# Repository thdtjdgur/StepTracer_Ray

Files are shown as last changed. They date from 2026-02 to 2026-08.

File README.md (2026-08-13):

# StepTracer_Ray

<p align="center">
  
  
  
  
</p>

StepTracer_Ray is a competition-oriented line tracer project built around repeated runs on the same track.
Instead of driving every lap with the same logic, the robot improves its strategy step by step: it first learns the course, then replays it faster, and finally applies more aggressive tuning for maximum performance.

That multi-stage race strategy is the core idea of this project.

## Hardware Image

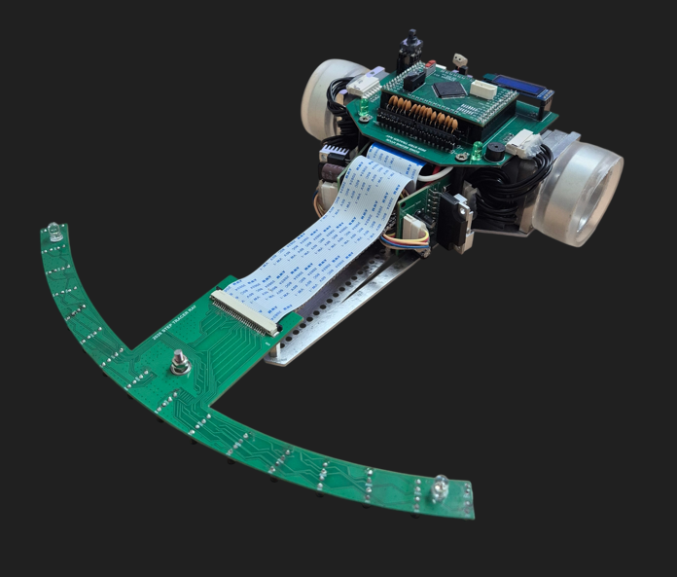
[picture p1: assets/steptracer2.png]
StepTracer hardware


## Demo Video

- 3rd race video: [`assets/videos/third-race.mp4`](assets/videos/third-race.mp4)

## PCB Files

- `HardWare/2025_PCB/`: archived PCB project files from the previous board set
- `HardWare/2026_PCB/`: updated PCB project files for `main_board.eprj`, `sensor_board.eprj`, and `motor_driver.eprj`

## Overview

The project is organized around three race stages:

- **1st race**: search and map generation
- **2nd race**: map-based fast replay
- **3rd race**: advanced tuning with trajectory shift and gain scheduling

The recorded race data is stored in `search_info[]`, which is then reused by the later runs.

## Race Strategy

### 1st Race - Search Run

The first race is the learning phase.

During this run, the robot follows the line while detecting turn marks, measuring distances between sections, and recording track information. The collected data is stored in `search_info[]` and later written to ROM so the next race can reuse the course map.

In short, the goal of the first race is reliable completion and track memorization.

### 2nd Race - Fast Run

The second race is the replay phase based on the recorded map.

After loading the saved track data, the robot classifies each section as straight, 45-degree turn, 90-degree turn, 180-degree turn, 270-degree turn, or large turn. Based on that information, it calculates acceleration, deceleration distance, entry speed, exit speed, and maximum speed for each segment.

Because the course is already known, the robot can drive more aggressively on straights and prepare for corners earlier than in the first race.

### 3rd Race - Extreme Run

The third race is the fully optimized performance phase.

This stage keeps the map-based replay logic from the second race, but adds more advanced tuning such as:

- target position shift before and after corners
- corner-group speed optimization
- adaptive `Kp` control
- more detailed acceleration planning

Instead of always following the line with the same center position, the robot intentionally shifts its trajectory depending on corner shape and surrounding track pattern. This allows faster and smoother cornering.

Related demo:

- 3rd race run video: [`assets/videos/third-race.mp4`](assets/videos/third-race.mp4)

## Core Modules

- `main.c`  
  System initialization and startup flow.

- `sensor.c`  
  Sensor sampling, normalization, line position calculation, cross detection, turn mark detection, and start/end detection.

- `Motor.c`  
  Motion control, distance accumulation, acceleration/deceleration logic, and third-race control behavior.

- `search.c`  
  First-race mapping logic.

- `fastrun.c`  
  Second-race speed planning and replay logic.

- `extremerun.c`  
  Third-race advanced tuning logic.

- `Rom.c`  
  Save/load logic for calibration data and recorded race data.

- `menu.c`  
  Menu interface for selecting race modes and tuning values.

## Technical Highlights

- 16-sensor line detection system
- weighted position calculation for smooth steering
- track memorization through first-run mapping
- turn classification based on recorded segment distance
- per-section velocity and deceleration planning
- third-run lateral shift and gain scheduling
- interrupt-driven sensor and motor control loop

## Position Low-Pass Filter

The STM32 control loop samples the line position every `200 us` (`5 kHz`). A first-order low-pass filter is used to reduce abrupt position changes and high-frequency sensor noise before the filtered position is used by the steering controller.

The continuous-time filter is

```text
         wc
H(s) = -------,    wc = 2*pi*Fc
       s + wc
```

Applying the Tustin transform

```text
    2   1 - z^-1
s = - * --------
    T   1 + z^-1
```

produces the discrete coefficients

```text
Kb = wc*T / (2 + wc*T)
Ka = (wc*T - 2) / (2 + wc*T)
```

and the difference equation

```text
y[n] = Kb * (x[n] + x[n-1]) - Ka * y[n-1]
```

which maps directly to C:

```c
filtered_position = Kb * (current_position + previous_position)
                    - Ka * previous_filtered_position;
```

With the current default `Fc = 80 Hz` and `T = 0.0002 s`, the coefficients are `Kb = 0.04786` and `Ka = -0.90428`. For a position step from `0` to `5000`, the filtered output starts approximately as `239 -> 695 -> 1107`, instead of jumping directly to `5000`.

The filtered position is used for the proportional term, while its sample-to-sample difference is used for the derivative term:

```text
P = Kp * y[n]
D = Kd * (y[n] - y[n-1])
```

The cutoff frequency `Fc` is adjustable from the OLED menu. Lower values provide stronger smoothing but slower response; higher values follow the line position faster but pass more sensor noise.

## Detailed Code Analysis

- Third-race deep dive: [`docs/extremerun-analysis.md`](docs/extremerun-analysis.md)
- Focus areas: `SofteWare/Initial_3rd_Code/main/extremerun.c` and `SofteWare/Initial_3rd_Code/main/Motor.c`

## Project Idea

This is not just a basic line follower. It is a staged racing system that combines sensing, memory, motion planning, and control tuning to improve lap performance across multiple runs.

The overall idea can be summarized as:

1. learn the course,
2. replay the course faster,
3. optimize the trajectory and control for the best run.

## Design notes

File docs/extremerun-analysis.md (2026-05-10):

# Extreme Run Code Analysis

This document explains how the third-race logic works in `SofteWare/Initial_3rd_Code/main/extremerun.c` and how that logic is executed at runtime by `SofteWare/Initial_3rd_Code/main/Motor.c`.

The third race is not just a faster second race. It adds a second layer of optimization on top of the saved map:

- straight-section acceleration is recomputed,
- corner groups get additional velocity shaping,
- lateral target shift is assigned per turn type,
- the shift is applied gradually before and after each segment midpoint,
- `Kp` is scheduled by track pattern instead of staying constant.

## Where the third race starts

The third race still enters through `fast_race()` in `SofteWare/Initial_3rd_Code/main/fastrun.c`.
When `third_val == 1`, the code runs the following pipeline before the robot starts moving:

1. `all_reset()`
2. `x_acc_func()`
3. `turn_maxvel_func()`
4. `x_maxvel_func()`
5. `chop_sdist_targetshift_func()`
6. `kp_division_func()`

After that, `StartCpuTimer2()` enables `CONTROL_ISR()`, which is the runtime loop that actually applies the third-race shift and gain scheduling.

## Key third-race fields in `search_info[]`

The third-race planner writes its results into each `race_info` entry:

- `iq10targetshift`: final lateral shift magnitude for that segment
- `iq10chop_targetshift`: one chopped piece of the target shift
- `iq10chop_shift_before`: shift increment used before the midpoint / before entering the next posture
- `iq10chop_shift_after`: shift increment used after the midpoint / while recovering or connecting to the next posture
- `iq15chop_sdist`: distance threshold that decides when the shift update begins inside the segment
- `DownFlag_U16`: whether the current pattern should drive `Kp` downward
- `Kp_UpDown_IQ17`: minimum scheduled `Kp` for the current pattern

These are later consumed by `CONTROL_ISR()` in `Motor.c`.

## Important default constants

These values are initialized mainly in `SofteWare/Initial_3rd_Code/main/search.c` and `SofteWare/Initial_3rd_Code/main/main.c`:

- `std_dist = 824`
- `iq15_chop_dist_amount = _IQ15(1000)`
- `iq10target_shift_large = _IQ10(1500)`
- `iq10target_shift_270 = _IQ10(2500)`
- `iq10target_shift_180 = _IQ10(2600)`
- `iq10target_shift_90 = _IQ10(6500)`
- `iq10target_shift_45 = _IQ10(5000)`
- `iq10target_shift_straight = _IQ10(2000)`
- `Curvature_difference = 0` by default

In practice, 90-degree turns receive the largest target shift, while large turns and straight recovery use smaller values.

## 1. `chop_sdist_targetshift_func()`

This pass assigns the shift plan for every segment.

### 1-1. What this code means

```c
_iq10 iq10_chop_shift_amount = _IQ10(1000);

pinfo->iq15chop_sdist = _IQ15div((pinfo->int32dist << 15) >> 1, iq15_chop_dist_amount);
if(((pinfo->int32dist + Curvature_difference) >> 1) < std_dist)
    iq10_chop_shift_amount = _IQ10div(
        iq10_chop_shift_amount,
        _IQ10div(std_dist << 10, (((pinfo->int32dist + Curvature_difference) << 10) >> 1))
    );
```

This block is the core of the chopped-shift planner.

- `iq10_chop_shift_amount` starts at `_IQ10(1000)`.
  - Conceptually, this is the divisor that determines how finely the target shift is sliced.
  - A larger divisor means smaller shift increments.
  - A smaller divisor means larger shift increments.

- `pinfo->iq15chop_sdist` is the distance threshold that decides when the shift update begins.
  - With the default `iq15_chop_dist_amount = _IQ15(1000)`, this becomes roughly **half of the segment distance** in IQ15 units.
  - So the third-race controller starts applying the chopped shift after about half of the segment has been traveled.

- The `if` condition checks whether **half of the adjusted segment distance** is shorter than `std_dist`.
  - Because `>>` has lower precedence than `+`, this expression is effectively:
    - `((int32dist + Curvature_difference) >> 1) < std_dist`
  - If the segment is short, the code reduces `iq10_chop_shift_amount`.

- Why reduce it?
  - Later, the code calculates `targetshift / iq10_chop_shift_amount`.
  - If the divisor becomes smaller, each chopped shift step becomes larger.
  - That means short segments apply the same lateral movement more aggressively, because there is less distance available to complete the shift.

So this block is a distance-adaptive smoothing rule:

- long segment -> smaller step per update
- short segment -> bigger step per update

### 1-2. Straight / end segment behavior

When the current segment is straight or end-turn:

- it recursively looks ahead to the next segment,
- inherits the next segment's `iq10targetshift`,
- calculates `iq10chop_shift_before` from the previous segment,
- calculates `iq10chop_shift_after` from the next segment.

This means the straight segment acts as the transition area between corners.

Instead of assigning a unique corner shift to the straight itself, the code uses the straight to:

- prepare for the previous corner's exit,
- prepare for the next corner's entry.

### 1-3. Same-direction consecutive turns

This block handles cases like right-straight-right or left-straight-left:

```c
if((((((pinfo-1)->int32turn_dir) & RIGHT_TURN) && (((pinfo+1)->int32turn_dir) & RIGHT_TURN)) ||
    ((((pinfo-1)->int32turn_dir) & LEFT_TURN) && (((pinfo+1)->int32turn_dir) & LEFT_TURN))) && (mark != 0))
```

The idea is simple:

- if two consecutive corners bend in the same direction,
- the robot should not fully return to the center and then shift again,
- it should connect those shifts more smoothly.

That is why the code sometimes uses the **difference** between neighboring `targetshift` values instead of the full previous value.

### 1-4. Opposite-direction transition case

There is also a special case for patterns that effectively behave like an S-curve:

```c
if((pinfo-1)->int32turn_way != (pinfo+1)->int32turn_way)
```

In this case the code avoids carrying too much previous-direction shift into the next opposite-direction turn.
It forces a more direct transition, often pulling the before-shift back toward zero.

### 1-5. Turn-type target shift assignment

For non-straight segments, the target shift is selected by turn class:

- `< TURN_90` -> use `iq10target_shift_45`
- `< TURN_180` -> use `iq10target_shift_90`
- `< TURN_270` -> use `iq10target_shift_180`
- `< LARGE_TURN` -> use `iq10target_shift_270`
- `END_TURN` -> use `iq10target_shift_straight`
- otherwise -> use `iq10target_shift_large`

This means the target shift is not derived from a continuous curvature estimate. It is chosen from a hand-tuned lookup by corner class.

### 1-6. `before` and `after` shift on actual turn segments

For a real turn segment:

- `iq10chop_shift_before` pushes the robot into the target posture before the turn fully develops,
- `iq10chop_shift_after` either:
  - continues the same-direction offset if another turn follows, or
  - starts recovering back toward center if the next segment is straight/end.

There is also a special half-shift rule for certain S-like combinations, which reduces the recovery amplitude to avoid overshoot.

## 2. `all_reset()`

This function resets every segment to a neutral third-race baseline.

For each `search_info[i]`, it:

- sets `int32accel = 3000`,
- sets `iq7in_vel`, `iq7vel`, and `iq7out_vel` to the base target velocity,
- clears `DownFlag_U16`,
- resets `Kp_UpDown_IQ17` to `PID_Kp_IQ17`,
- clears the chopped shift fields.

So `all_reset()` is not the final plan. It is the clean starting point before each specialized planner rewrites selected fields.

## 3. `turn_maxvel_func()` and `turn_maxvel_compute()`

This pass handles grouped-corner velocity shaping.

The main idea is:

- if several short connected turns appear close together,
- treat them as one corner group,
- compute a shared acceleration level and a shared bridge velocity.

The function uses `x_count` and `int32x_dist` to accumulate consecutive related segments.

### What it is trying to do

- skip segments that are too sharp or not useful for grouping,
- collect consecutive corner-group distance into `int32x_dist`,
- choose `int32accel` from `X_SHORT_DIST`, `X_MID_DIST`, `X_LONG_DIST`,
- compute `iq7x_vel` with `X_vel_compute()`,
- propagate that velocity as:
  - current segment `out_vel`,
  - next segment `in_vel`.

This creates smoother corner-to-corner connection speed than the plain second-race planner.

## 4. `X_vel_compute()`

This function is a third-race-specific maximum-velocity helper.

It uses the same kinematic idea as the normal fast-run planner:

- `v_next = sqrt(v_current^2 + 2 a s)`

Then it clamps the result:

- upper bound: `_IQ7(2500.0)`
- lower bound: base target velocity

So this function computes a bounded bridge velocity for grouped-corner logic.

## 5. `x_acc_func()` and `x_straight_compute()`

This pass recomputes acceleration for straight and end-turn sections only.

The logic is still distance-bucket based:

- `LONG_DIST` -> use `g_int32long_ACC + long_accel`
- `MID_DIST` -> use `g_int32mid_ACC + mid_accel`
- otherwise -> use `g_int32short_ACC + short_accel`

Special handling:

- the very first segment gets `3500 + start_accel`,
- the end segment is forced down to `2800`.

This pass is important because the third-race planner later recomputes max velocity on top of these new acceleration values.

## 6. `x_maxvel_func()` and `x_maxvel_compute()`

This pass recalculates straight-section velocity and deceleration distance after the third-race acceleration adjustments.

The flow is:

1. compare `iq7in_vel` and `iq7out_vel`
2. compute the minimum distance required to connect them via `decel_dist_compute()`
3. if the segment is too short, solve directly for reachable max velocity
4. otherwise, compute a higher `iq7vel` and then compute `iq7dec_dist`

This is the third-race version of straight-section speed planning, applied after grouped-corner tuning has already modified some boundary velocities.

## 7. `kp_division_func()` and `kp_division_compute()`

This pass schedules `Kp` according to corner pattern.

### Big picture

The intent is:

- simple or isolated sections keep the default `PID_Kp_IQ17`,
- dense corner patterns lower `Kp` in a controlled way,
- sharp transitions receive a more aggressive minimum `Kp` profile.

### Pattern examples

The code explicitly handles pattern families such as:

- straight-short-45
- 45-45
- 45-45-45-45
- 45-90 combinations
- 90-45 combinations
- 90-90 combinations

And it assigns tuned constants such as:

- `Kp_S4_IQ17`
- `Kp_SHORT_S44S_IQ17`
- `Kp_long_S44S_IQ17`
- `Kp_S4444S_IQ17`
- `Kp_SHARP_TURN_IQ17`
- `Kp_S9999S_IQ17`

`DownFlag_U16` marks whether the runtime controller should move `HanPID.Kp_val_IQ17` downward toward the chosen minimum.

### Important note

This line is logically wrong:

```c
if(search_info[i].int32turn_dir != STRAIGHT || search_info[i].int32turn_dir != END_TURN)
```

It is always true, because one value cannot be both `STRAIGHT` and `END_TURN` at the same time.
The condition almost certainly should have been `&&` instead of `||`.

So `kp_division_compute()` currently runs for every segment, even when the author probably intended to filter out straight/end segments.

## 8. `xCONTROL()`

This function is the runtime `Kp` ramp controller.

Inputs:

- `mode`
- `ratio`
- `kp_min`

Behavior:

- `mode == OFF`
  - increase `Kp_val_IQ17` toward `PID_Kp_IQ17`
- `mode == ON`
  - decrease `Kp_val_IQ17` toward `kp_min`

The per-update step size is:

```c
_IQ17mpy(ratio, _IQ17(0.823882502))
```

The `0.823882502` constant matches the per-step travel distance used elsewhere in the code. So the ramp is effectively distance-based, even though it is applied inside an interrupt loop.

This is a key design choice: the code tries to make `Kp` transition with travel progress, not as a one-shot jump.

## 9. `underdist()`

This helper precomputes error thresholds used during replay:

- `under_dist = 70% of expected segment distance`
- `err_dist = expected segment distance + 150 mm`

So the third-race error logic has both:

- an early-arrival threshold,
- an overrun threshold.

## 10. Runtime behavior in `Motor.c::CONTROL_ISR()`

This is where the third-race plan becomes actual control output.

## 10-1. `Kp` ramp application

At the top of the ISR:

```c
if(search_info[U16_3rd_turnmark_cnt].DownFlag_U16)
    xCONTROL(ON, &HanPID, KP_D_RATIO_IQ17, search_info[U16_3rd_turnmark_cnt].Kp_UpDown_IQ17);
else
    xCONTROL(OFF, &HanPID, KP_U_RATIO_IQ17, search_info[U16_3rd_turnmark_cnt].Kp_UpDown_IQ17);
```

Meaning:

- if the current pattern requires `Kp` reduction, move toward the segment-specific minimum,
- otherwise recover back toward the normal base `Kp`.

So `kp_division_compute()` is the planner, and `xCONTROL()` inside `CONTROL_ISR()` is the actuator.

## 10-2. Per-segment distance reset

When `third_turnmark_flag` is `OFF`, the ISR resets:

- `LMotor.iq15third_gone_dist`
- `RMotor.iq15third_gone_dist`

Then it sets `third_turnmark_flag = ON`.

This creates a fresh local distance counter for the current third-race segment.

## 10-3. Before / after split

The ISR calculates:

- `iq15third_dist_sum`: local distance used against `iq15chop_sdist`
- `iq15third_dist_sum_dupli`: average real distance used for before/after classification

Then it decides:

- `before = ON`, `after = OFF` if current progress is still in the first half of the segment
- otherwise `before = OFF`, `after = ON`

So the segment is split into two logical zones around its midpoint.

## 10-4. When the shift actually starts

The ISR does **not** update `iq10position_shift` immediately.
It first waits until:

```c
iq15third_dist_sum > search_info[U16_3rd_turnmark_cnt].iq15chop_sdist
```

Since `iq15chop_sdist` is roughly half the segment distance, this means the actual shift update starts around the second half of the local segment progress.

That prevents abrupt lateral movement immediately after a mark transition.

## 10-5. Straight / end segment shift update

If the current segment is straight or end-turn:

- `before` applies `iq10chop_shift_before`
- `after` applies `iq10chop_shift_after`

Then the code clamps `iq10position_shift` so it does not overshoot the allowed target derived from neighboring corners.

This is why the straight segment behaves like a transition buffer between turns.

## 10-6. Actual turn segment shift update

If the current segment is a turn:

- `before` moves the shift toward the current turn's target posture,
- `after` either recovers toward straight or connects to the next turn posture,
- additional clamps limit overshoot for same-direction chains and opposite-direction patterns.

So the runtime shift is not a single setpoint jump. It is a staged position migration with context-aware saturation.

## 10-7. Why `g_Flag.third_turnmark_flag` is cleared at the end

At the end of the update block:

```c
g_Flag.third_turnmark_flag = OFF;
```

This forces the next cycle after a segment transition to reset the local third-race distance counters again.
That is how each segment gets its own local shift timing window.

## Putting it all together

The full third-race behavior is:

1. reuse the first-race map and second-race turn classification
2. re-plan straight acceleration and grouped-corner speed
3. assign a lateral target shift by turn class
4. break that shift into before/after chopped increments
5. schedule `Kp` by corner pattern
6. inside `CONTROL_ISR()`, ramp `Kp` and apply lateral shift gradually based on segment progress

In other words, the third race does not simply "go faster." It changes how the robot places itself on the line and how stiffly it responds while entering, connecting, and leaving corner patterns.

## Important quirks and possible issues

- `kp_division_func()` uses an always-true `||` condition and likely needs `&&`.
- Several expressions in `turn_maxvel_compute()` rely on mixed `&&` and `||` without extra parentheses, so the actual grouping may not exactly match the author's comments.
- The planner is heavily pattern-based and hand-tuned, so behavior depends strongly on the exact turn classification from the second-race map.
- The straight recursion in `chop_sdist_targetshift_compute()` assumes a valid next entry exists; this works only if the race table has been built consistently.

## Bottom line

`extremerun.c` is a post-planner for the third race.
It does three main things:

- rebuilds speed decisions for difficult corner groups,
- precomputes how much lateral shift each segment should create,
- precomputes how `Kp` should be lowered and restored.

`Motor.c::CONTROL_ISR()` is the executor.
It applies those plans gradually while the robot is physically moving through each segment.

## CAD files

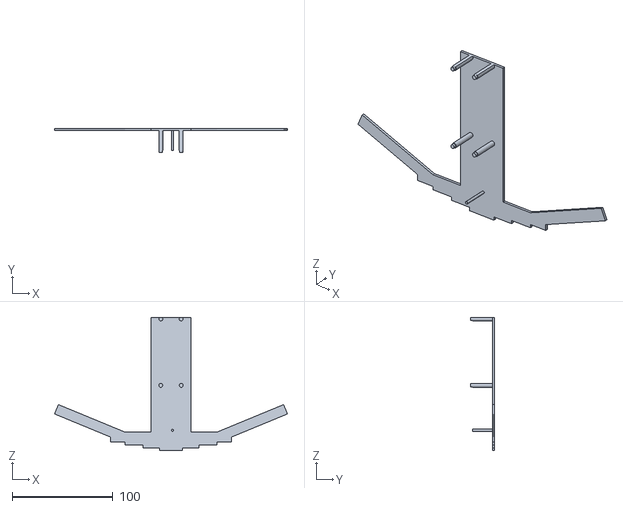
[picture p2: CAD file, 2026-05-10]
Mechanics/STL/송성혁_센서보드.STL
231.6 x 24.0 x 132.6

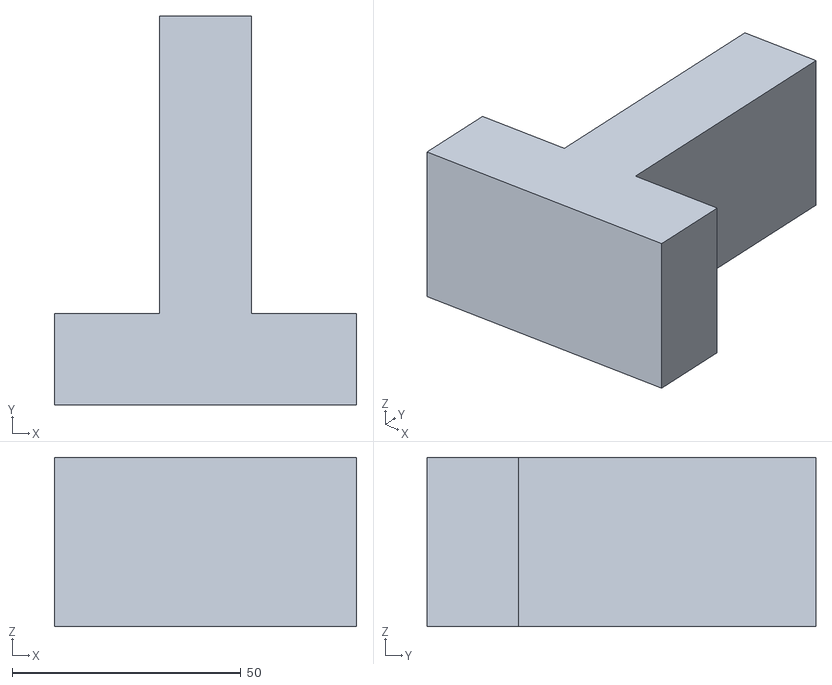
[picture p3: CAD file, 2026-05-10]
Mechanics/STL/송성혁_배터리.STL
66.0 x 85.0 x 37.0

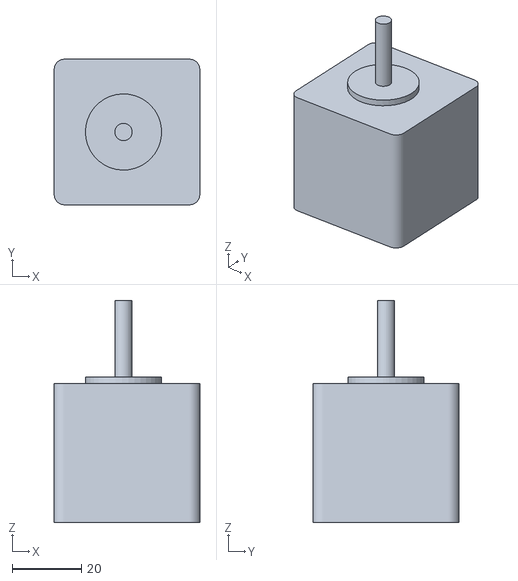
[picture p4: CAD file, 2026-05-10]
Mechanics/STL/송성혁_모터.STL
42.0 x 42.0 x 64.0

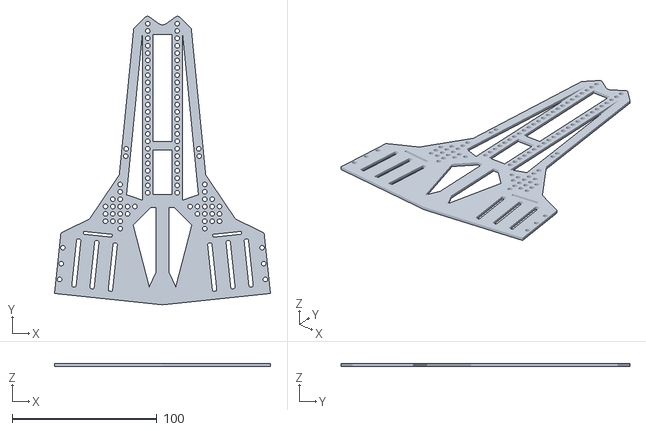
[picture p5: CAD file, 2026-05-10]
Mechanics/STL/26년 스텝밑판.STL
149.2 x 199.3 x 2.00

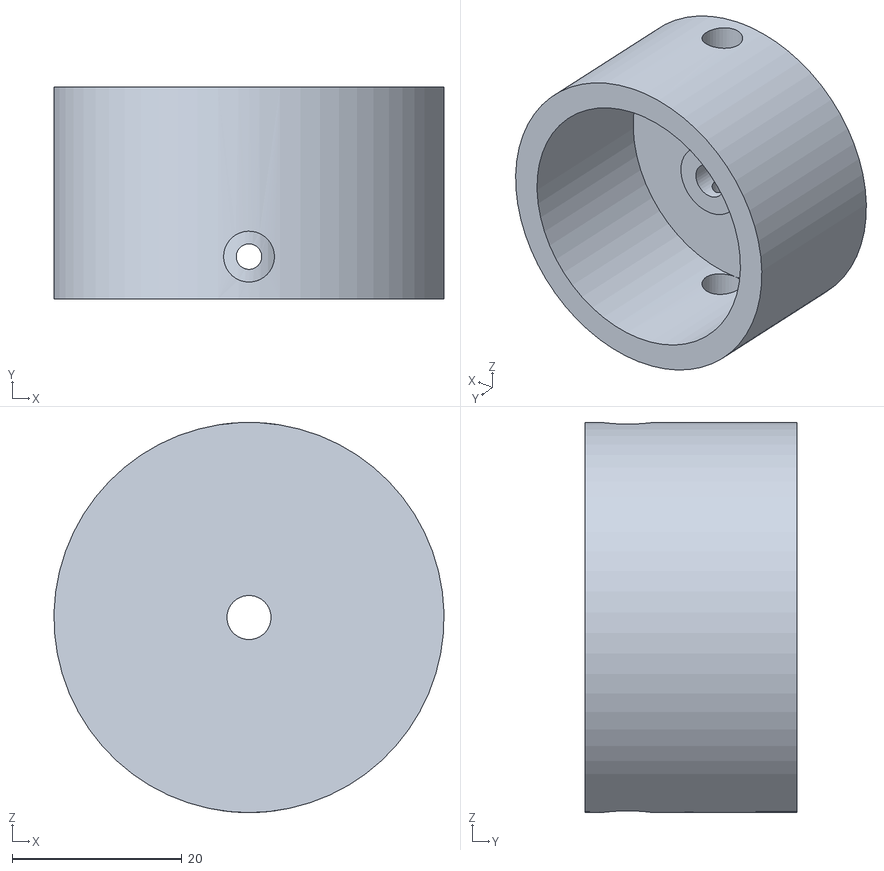
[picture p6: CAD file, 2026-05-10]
Mechanics/STL/송성혁_바퀴.STL
46.0 x 25.0 x 46.0

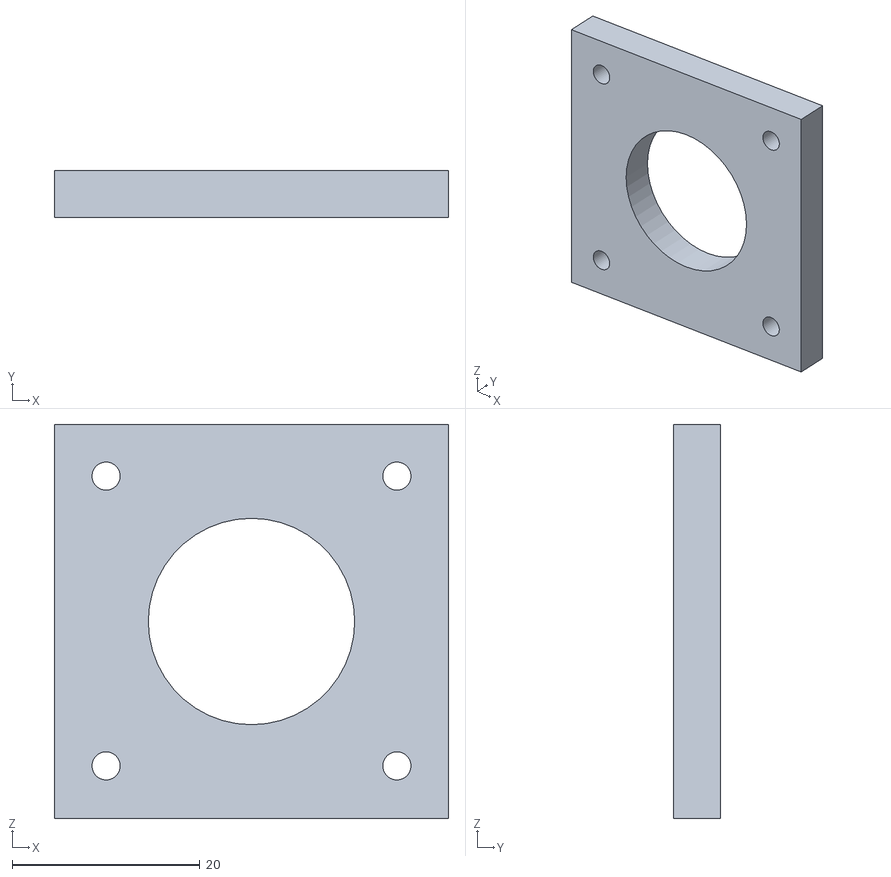
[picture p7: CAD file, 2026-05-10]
Mechanics/STL/송성혁_가드.STL
42.0 x 5.00 x 42.0

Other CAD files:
SofteWare/Tms_Initial_3rd_Code/main/main.obj
SofteWare/2025_dankook_code/main/main.obj
SofteWare/Tms_Initial_3rd_Code/main/DSP280x_CpuTimers.obj
SofteWare/Tms_Initial_3rd_Code/main/DSP280x_Sci.obj
SofteWare/Tms_Initial_3rd_Code/main/extremerun.obj
SofteWare/Tms_Initial_3rd_Code/main/DSP280x_usDelay.obj
SofteWare/Tms_Initial_3rd_Code/main/VFD.obj
SofteWare/Tms_Initial_3rd_Code/main/DSP280x_PieCtrl.obj
SofteWare/Tms_Initial_3rd_Code/main/search.obj
SofteWare/Tms_Initial_3rd_Code/main/DSP280x_Adc.obj
SofteWare/Tms_Initial_3rd_Code/main/Motor.obj
SofteWare/Tms_Initial_3rd_Code/main/DSP280x_MemCopy.obj
SofteWare/2025_dankook_code/main/DSP280x_Adc.obj
SofteWare/2025_dankook_code/main/DSP280x_CodeStartBranch.obj
SofteWare/2025_dankook_code/main/DSP280x_CpuTimers.obj
SofteWare/2025_dankook_code/main/DSP280x_DefaultIsr.obj
SofteWare/2025_dankook_code/main/DSP280x_EPwm.obj
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

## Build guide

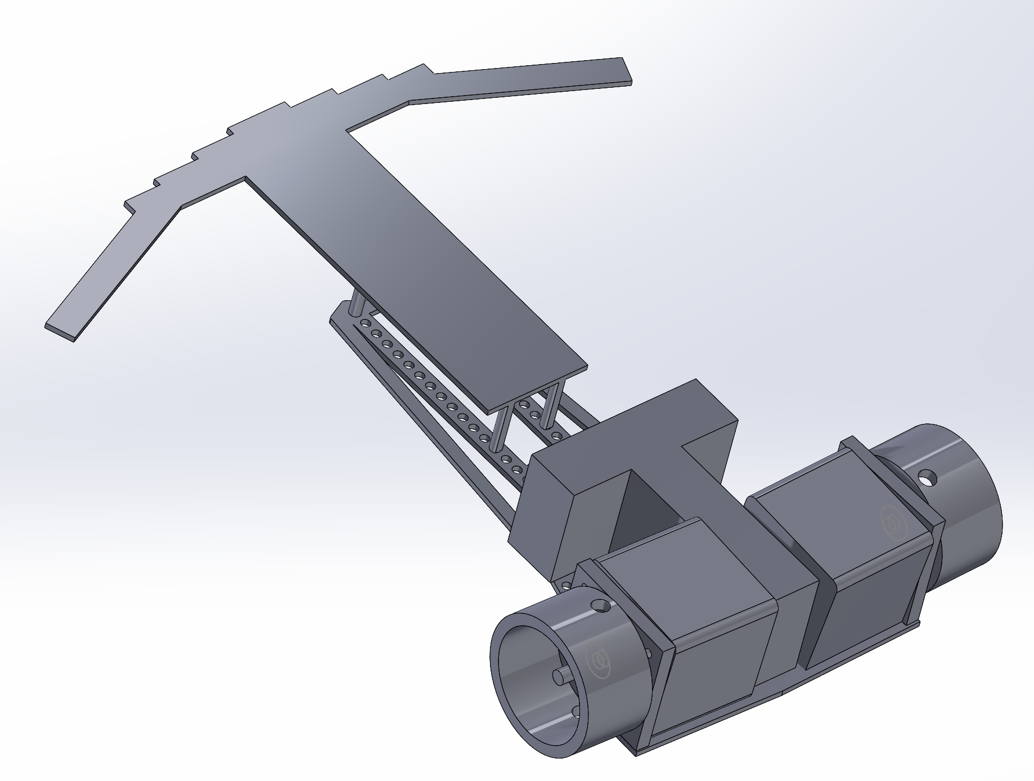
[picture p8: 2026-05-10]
Mechanics/Assembly.png

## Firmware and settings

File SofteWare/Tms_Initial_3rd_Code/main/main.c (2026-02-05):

#define _MAIN_
#define __STRUCT__


#include "DSP280x_Device.h"     // DSP281x Headerfile Include File
#include "DSP280x_Examples.h"  // DSP281x Examples Include File

void System_Init(void)
{
	DINT;				// 전체 인터럽트 금지
	InitSysCtrl();		// 워치록 금지, PLL 초기화, 주변 장치 클럭설정
	InitGpio();			// 입출력 포트 초기화	
	InitCpuTimers();
	
	MemCopy(&RamfuncsLoadStart, 	&RamfuncsLoadEnd, 		&RamfuncsRunStart); 
	MemCopy(&RamfuncsLoadStart1, 	&RamfuncsLoadEnd1, 	&RamfuncsRunStart1);
	
	InitSci();			
	InitSpi();
	InitPieCtrl();		// PIE 제어 레지스터 초기화 동작
	IER = 0x0000;		// 인터럽트 인에이블 레지스터 클리어
	IFR = 0x0000;		// 인터럽트 플래그 레지스터 클리어
	InitPieVectTable();
	InitAdc();

	Init_ISR();

	InitEPWM( &LeftPwmRegs );
	InitEPWM( &RightPwmRegs );
	
	InitEQep( &LeftQepRegs );
	InitEQep( &RightQepRegs );
	
}

void Variable_Init( void )
{
    memset( ( void * )search_info, 0x00, sizeof( race_info ) * 256 );//초기화 함수
	g_int32_sen_cnt = 0;
	g_int32_copmare_cnt = 0;
	g_u16pos_cnt=6;
	
	g_pos.iq10temp_position= _IQ10(0.0);
	g_pos.iq7temp_pos = _IQ7(0.0);
	g_u16pos_cnt=6;
	g_int32_turnmark_cnt = 0;
	g_int32_lineout_cnt = 0;
	g_int32_start_end_cnt = 0;
	g_u32_ACC_targetval=3700;//트레이서 가속도 
	g_u32_VEL_targetval=2000;//트레이서 속도//2200
	g_u32_END_ACC_targetval = 9000;//(g_u32_VEL_targetval * g_u32_VEL_targetval / 435);//2as==v^2-v0^2 에서 가속도를 구하는 공식 

	g_q17_handle_acc = _IQ17(0.00002960);
	g_q17_handle_dec = _IQ17(0.0002560);//올려보자	
	g_Flag.motor = OFF;
	interrupt_flag = ON;
	
	g_u16turn_dist = T___dist = 67;//65:txprint잛은거임//txprint긴거 할대는 60가지 줄이기
	third_dist_err = 100;//조금더 시프팅을 일직하고싶다면 늘리기. 가상의 턴마크를 옮기는 역할
	Curvature_difference = 0;//50//실제곡률과 3차주행의 곡률차. 너무 발리 after에서 중앙으로 복귀하면 늘리기
	//serial plot의 shfit의 윗부분이 사다리골 모양이면 사다리골 윗부분을 곡짓점으로 만들기 위해 늘려야함(시프트변화속도를 늦춘다)
	//근데 곡짓점(경사가 완만 )이 되면 곡선의 완전 처음부분에서 곡선을 다라가는 경향이 생겨서 어느정도 사다리골이 되어야함 
	//즉 곡선을 다라간다싶으면 안다라가게 하기위해 줄이기 
    
    Turn_Cnt = 147;//147
	g_u32_second_END_ACC_targetval = 11500;
	end_cnt = 0;

	error = 0;
	end_accel = start_accel = long_accel = mid_accel = short_accel = 0;

    g_err.int32err_cnt = 0;
        
	acc = 0;
	dec = 0;

	second_val = 0;
	third_val = 0;
}

void main(void)
{	
	int i;

	System_Init();
	Variable_Init();
	StartCpuTimer0();
	Race_Init();
	sen_vari_init();	
	maxmin_read_rom();
	read_mark_cnt_rom();
	//StartCpuTimer2();
	//LED_ALL_OFF33;

	VFD_SENSOR();

}


void Delay(Uint32 Cnt)
{
	while(Cnt--)
	{
		asm("		nop");
		
		asm("	nop");	
	}
}

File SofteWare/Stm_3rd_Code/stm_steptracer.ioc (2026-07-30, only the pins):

Mcu.UserName=STM32G474VETx
PA0.Signal=ADC1_IN1
PA1.Signal=ADC1_IN2
PA10.Signal=USART1_RX
PA11.Signal=GPIO_Output
PA12.Signal=GPIO_Output
PA13.Signal=SYS_JTMS-SWDIO
PA14.Signal=SYS_JTCK-SWCLK
PA2.Signal=ADC1_IN3
PA3.Signal=ADC1_IN4
PA4.Signal=ADC2_IN17
PA5.Signal=ADC2_IN13
PA6.Signal=ADC2_IN3
PA7.Signal=ADC2_IN4
PA8.Signal=GPIO_Output
PA9.Signal=USART1_TX
PB0.Signal=ADC1_IN15
PB1.Signal=ADC1_IN12
PB2.Signal=S_TIM20_CH1
PB3.Signal=SPI1_SCK
PB4.Signal=SPI1_MISO
PB5.Signal=SPI1_MOSI
PC0.Signal=ADC1_IN6
PC1.Signal=ADC1_IN7
PC11.Signal=GPIO_Output
PC14-OSC32_IN.Signal=GPIO_Input
PC15-OSC32_OUT.Signal=GPIO_Input
PC2.Signal=ADC1_IN8
PC3.Signal=ADC1_IN9
PC4.Signal=ADC2_IN5
PC5.Signal=ADC2_IN11
PC6.Signal=S_TIM8_CH1
PC7.Signal=GPIO_Output
PC8.Signal=I2C3_SCL
PC9.Signal=I2C3_SDA
PD10.Signal=GPIO_Output
PD11.Signal=GPIO_Output
PD12.Signal=GPIO_Output
PD13.Signal=GPIO_Output
PD14.Signal=GPIO_Output
PD15.Signal=GPIO_Output
PD7.Signal=GPIO_Output
PD8.Signal=GPIO_Output
PD9.Signal=GPIO_Output
PE8.Signal=GPIO_Output
PE9.Signal=GPIO_Output
PF0-OSC_IN.Signal=RCC_OSC_IN
PF10.Signal=GPIO_Input
PF2.Signal=GPIO_Output
PF9.Signal=GPIO_Input

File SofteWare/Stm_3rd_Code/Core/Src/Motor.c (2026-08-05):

#include "Motor.h"

#include "extremerun.h"
#include "stm32g4xx_ll_cortex.h"
#include "stm32g4xx_ll_tim.h"

#include <math.h>
#include <string.h>

extern TIM_HandleTypeDef htim7;
extern TIM_HandleTypeDef htim8;
extern TIM_HandleTypeDef htim20;

#define LEFT_MOTOR_STOP_GPIO_Port   GPIOA
#define LEFT_MOTOR_STOP_Pin         GPIO_PIN_8
#define LEFT_MOTOR_DIR_GPIO_Port    GPIOC
#define LEFT_MOTOR_DIR_Pin          GPIO_PIN_7

#define RIGHT_MOTOR_STOP_GPIO_Port  GPIOE
#define RIGHT_MOTOR_STOP_Pin        GPIO_PIN_8
#define RIGHT_MOTOR_DIR_GPIO_Port   GPIOE
#define RIGHT_MOTOR_DIR_Pin         GPIO_PIN_9

#define MOTOR_STOP_ENABLE_STATE     GPIO_PIN_RESET
#define MOTOR_STOP_DISABLE_STATE    GPIO_PIN_SET

#define LEFT_MOTOR_FORWARD_STATE    GPIO_PIN_RESET
#define RIGHT_MOTOR_FORWARD_STATE   GPIO_PIN_SET

#define MOTOR_TIMER_CLOCK_FALLBACK  170000000u
#define MOTOR_START_VELO_MM_S     100.0f
#define STM_THIRD_CONTROL_PERIOD_US 150.0f
#define TMS_THIRD_CONTROL_PERIOD_US 200.0f
#define THIRD_KP_PERIOD_SCALE \
    (STM_THIRD_CONTROL_PERIOD_US / TMS_THIRD_CONTROL_PERIOD_US)

volatile MOTORCTRL LMotor;
volatile MOTORCTRL RMotor;

volatile uint32_t JERK_U32 = 8000u;
volatile uint32_t JERK_LONG_U32 = 20000u;
volatile uint32_t JERK_MIDDLE_U32 = 25000u;
volatile uint32_t JERK_SHORT_U32 = 30000u;

volatile uint32_t MOTOR_SPEED_U32 = 2000u;
volatile uint32_t SECOND_MAX_SPEED_U32 = 4000u;
volatile uint32_t END_SPEED_U32 = 2000u;

volatile int32_t ACCEL_COEF_I32 = 296;
volatile int32_t DECEL_COEF_I32 = 256;
volatile int32_t D_RATIO_I32 = 3.5;
volatile int32_t U_RATIO_I32 = 3.5;
volatile uint32_t Down_Kp_U32 = 5u;
volatile uint32_t SHARP_KP_U32 = 40u;   //30u
volatile uint32_t S44S_KP_U32 = 72u;
volatile uint32_t S44S_short_KP_U32 = 16u;//6u
volatile uint32_t S44S_long_KP_U32 = 16u;//6u
volatile uint32_t S4444S_KP_U32 = 47u;  //37u
volatile uint32_t S4_KP_U32 = 35u;  //29u
volatile uint32_t S9999S_KP_U32 = 5u;
volatile uint32_t mid_long_straight = 47u;//37u
volatile uint32_t short_straight = 47u;//37u 
volatile uint32_t s44s_end_s = 50u;

static uint32_t motor_timer_clock_hz = MOTOR_TIMER_CLOCK_FALLBACK;

static volatile float control_last_distance;
static volatile float control_shift_distance;
static volatile float control_position_shift;
static volatile uint16_t control_segment;
static volatile uint16_t control_soft_safe_active;
static volatile uint16_t control_soft_safe_start_segment;

static uint16_t control_total_count(void)
{
    if (g_int32total_cnt < 0)
    {
        return 0u;
    }
    if (g_int32total_cnt > 253)
    {
        return 253u;
    }
    return (uint16_t)g_int32total_cnt;
}

static float motor_clamp_float(float value, float min_value, float max_value)
{
    if (value < min_value)
    {
        return min_value;
    }

    if (value > max_value)
    {
        return max_value;
    }

    return value;
}

static float motor_valid_handle(float handle)
{
    if (!isfinite(handle))
    {
        return 1.0f;
    }

    return (handle < 0.0f) ? 0.0f : handle;
}

static uint32_t motor_get_apb2_timer_clock_hz(void)
{
    uint32_t pclk = HAL_RCC_GetPCLK2Freq();
    if (pclk == 0u)
    {
        return MOTOR_TIMER_CLOCK_FALLBACK;
    }

    if ((RCC->CFGR & RCC_CFGR_PPRE2) != RCC_CFGR_PPRE2_DIV1)
    {
        pclk *= 2u;
    }

    return pclk;
}

static float motor_min_period_counts(void)
{
    return (MOTOR_STEP_DISTANCE_MM / MAX_VELO) * (float)motor_timer_clock_hz;
}

static float motor_max_period_counts(void)
{
    return (float)MOTOR_TIMER_MAX_PERIOD_TICKS *
           (float)(1u << CLK_DIVISION_CONSTANT);
}

static float motor_period_seconds_from_ctrl(volatile MOTORCTRL *pM)
{
    float raw_counts = pM->PwmTBPRDdiv10000 * 10000.0f;
    if (raw_counts <= 0.0f)
    {
        raw_counts = motor_max_period_counts();
    }

    return raw_counts / (float)motor_timer_clock_hz;
}

static float motor_raw_counts_from_velocity(float velocity_mm_s)
{
    float velocity = motor_clamp_float(velocity_mm_s, MIN_VELO, MAX_VELO);
    return (MOTOR_STEP_DISTANCE_MM / velocity) * (float)motor_timer_clock_hz;
}

static void motor_apply_period_counts(volatile MOTORCTRL *pM, TIM_HandleTypeDef *htim, float raw_counts)
{
    uint8_t clk = pM->ClkDiv;
    const float min_counts = motor_min_period_counts();
    const float max_counts = motor_max_period_counts();
    uint32_t divider;
    uint32_t old_prescaler;
    uint32_t new_prescaler;
    uint32_t period_ticks;
    uint32_t arr;

    raw_counts = motor_clamp_float(raw_counts, min_counts, max_counts);

    while ((clk > 0u) && (raw_counts < (min_counts * (float)(1u << clk))))
    {
        clk--;
    }

    while ((clk < CLK_DIVISION_CONSTANT) &&
           (raw_counts > ((float)MOTOR_TIMER_MAX_PERIOD_TICKS *
                          (float)(1u << clk))))
    {
        clk++;
    }

    divider = 1u << clk;
    period_ticks = (uint32_t)((raw_counts / (float)divider) + 0.5f);

    if (period_ticks < 1u)
    {
        period_ticks = 1u;
    }
    else if (period_ticks > MOTOR_TIMER_MAX_PERIOD_TICKS)
    {
        period_ticks = MOTOR_TIMER_MAX_PERIOD_TICKS;
    }
    arr = period_ticks - 1u;

    pM->ClkDiv = clk;
    pM->PwmTBPRDdiv10000 = raw_counts / 10000.0f;
    pM->PrdNext = period_ticks;

    old_prescaler = htim->Instance->PSC;
    new_prescaler = divider - 1u;
    htim->Instance->PSC = new_prescaler;
    htim->Instance->ARR = arr;
    htim->Instance->CCR1 = period_ticks >> 1;

    if ((htim->Instance->CR1 & TIM_CR1_CEN) == 0u)
    {
        htim->Instance->CNT = 0u;
        htim->Instance->EGR = TIM_EGR_UG;
        htim->Instance->SR &= ~TIM_SR_UIF;
    }
    else if (old_prescaler != new_prescaler)
    {
        const uint32_t original_urs = htim->Instance->CR1 & TIM_CR1_URS;

        SET_BIT(htim->Instance->CR1, TIM_CR1_URS);
        htim->Instance->EGR = TIM_EGR_UG;
        htim->Instance->SR &= ~TIM_SR_UIF;
        if (original_urs == 0u)
        {
            CLEAR_BIT(htim->Instance->CR1, TIM_CR1_URS);
        }
    }
}

static uint32_t motor_profile_lock(void)
{
    const uint32_t primask = __get_PRIMASK();

    __disable_irq();
    return primask;
}

static void motor_profile_unlock(uint32_t primask)
{
    if (primask == 0u)
    {
        __enable_irq();
    }
}

static uint8_t motor_pwm_is_running(void)
{
    return (((htim8.Instance->CR1 & TIM_CR1_CEN) != 0u) &&
            ((htim20.Instance->CR1 & TIM_CR1_CEN) != 0u) &&
            (g_Flag.motor != OFF))
               ? 1u
               : 0u;
}

static float motor_start_velocity_for_target(float target_velocity)
{
    if (target_velocity <= MIN_VELO)
    {
        return 0.0f;
    }

    return (target_velocity < MOTOR_START_VELO_MM_S)
               ? target_velocity
               : MOTOR_START_VELO_MM_S;
}
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

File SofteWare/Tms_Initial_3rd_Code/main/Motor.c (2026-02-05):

//###########################################################################
//
// FILE		: Motor.c
//
// TITLE	: Motor c file.
//
// Author	: Yuk Keun Ho
//
// Company	: Maze & Hz
//
//###########################################################################
// $Release Date: 2011.10.16 $
//###########################################################################

#define   _MOTOR_


#include "DSP280x_Device.h"
#include "DSP280x_Examples.h"   // DSP280x Examples Include File
#include "Main.h"
#include "Motor.h"

void R_VELOCITY(void)
{
	VFDPrintf("v=%lu",g_u32_VEL_targetval);

    while(1)
    	{
    	while(1)
    		{    

	            if((SW_R==0)||(SW_L==0))// right
	            {
                    if(SW_R==0)// right
	                {
	                    DELAY_US(SW_DELAY);
		                g_u32_VEL_targetval+=50;
                    }
                    else if(SW_L==0)// right
	                {
	                    DELAY_US(SW_DELAY);
		                g_u32_VEL_targetval-=50;
                    }
					
                    VFDPrintf("v=%lu",g_u32_VEL_targetval);

					if(g_u32_VEL_targetval==1600) //속도 1600
				    {
						g_q17_handle_acc = _IQ17(0.00002970);
						g_q17_handle_dec = _IQ17(0.0002550);
					}
				    else if(g_u32_VEL_targetval==1800)//속도 1800
				    {
                        g_q17_handle_acc = _IQ17(0.00003040);
	                    g_q17_handle_dec = _IQ17(0.0002500);
					}
                    else if(g_u32_VEL_targetval==1900)//속도 1900
				    {
                        g_q17_handle_acc = _IQ17(0.00003030);//3040
	                    g_q17_handle_dec = _IQ17(0.0002670);//2500
					}
					else if(g_u32_VEL_targetval==2000)
				    {
                        g_q17_handle_acc = _IQ17(0.00003025);//3025
	                    g_q17_handle_dec = _IQ17(0.0002660);//2660
					}
					else if(g_u32_VEL_targetval==2100)//속도 2100
				    {
                        g_q17_handle_acc = _IQ17(0.00003080);//3003
	                    g_q17_handle_dec = _IQ17(0.0002500);//
					}
					else if(g_u32_VEL_targetval==2200)//속도 2200
				    {
                        g_q17_handle_acc = _IQ17(0.00003003);//3003
	                    g_q17_handle_dec = _IQ17(0.0002641);//2641
	                    g_q17_handle_dec += 12;//+1
					}
					else if(g_u32_VEL_targetval==2300)//속도 2300//acc만  1내리니가 잘감
				    {
				      	g_q17_handle_acc = _IQ17(0.00002998);// 2올림 5올림 //2998//7
				      	g_q17_handle_acc -= 0;//-1
	                    g_q17_handle_dec = _IQ17(0.0002603);// 5올림 2올림 //52
	                    g_q17_handle_dec += 18;// 12,14,16   //16, 14
					}
					else if(g_u32_VEL_targetval==2350)//속도 2350
				    {
				      	g_q17_handle_acc = _IQ17(0.00002998);// 2올림 5올림 //2998
				      	g_q17_handle_acc -= 0;//-1
	                    g_q17_handle_dec = _IQ17(0.0002603);// 5올림 2올림 
	                    g_q17_handle_dec += 0;//5, 7,8, 6666, 55555555555555555, 7777777777777낫베드, 4낫베드, 2낫베드, 1낫베드,3
					}
					else if(g_u32_VEL_targetval==2400) //acc만 2내리니가 잘감//살작 불안정함 acc를 1내리고 dec를 1올려보자.
				    {
				      	g_q17_handle_acc = _IQ17(0.00002990);//0.00002990
						g_q17_handle_acc -= 3;// -3
	                    g_q17_handle_dec = _IQ17(0.0002570);
						g_q17_handle_dec += 4;// +8(올리면 올릴수록 물방울에서 더 안죽음, 근데 올리다 보면 통통튐....5,6정도가 많이 튕기진 않는데 물방울에서 위태위태함)
					}
					else
	                {
	                    VFDPrintf("v=%lu",g_u32_VEL_targetval);
	                }
	            }


	            else if(SW_D==0)
	            {
	            	DELAY_US(SW_DELAY);
	            	VFDPrintf("v=%lu",g_u32_VEL_targetval);
			    	break;
	            }

				else if(SW_U==0)
				{
					DELAY_US(SW_DELAY);
					VFD_RUN();
				}
			
	            else
	            {
	            	VFDPrintf("v=%lu",g_u32_VEL_targetval);
	            }
                
    		}
         	//write_vel_rom();
		 	break;
    	}	
	R_MOT_A();	
}



void R_MOT_A(void)// 증가 가속도 조절 함수 
{
	VFDPrintf("HanAccel");
    while(1)
    	{
    	while(1)
    		{
    		    DELAY_US(100000);
	            if(SW_R==0)//right
	            {
	            	DELAY_US(50000);
		        	g_q17_handle_acc += 1;
                	acc+=1;
                	VFDPrintf("acc_%d   ",acc);
	            }

	            else if(SW_L==0)//left
	            {
	            	DELAY_US(50000);
		        	g_q17_handle_acc -= 1;
                	acc-=1;
                	VFDPrintf("acc_%d   ",acc);
		        }

	            else if(SW_D==0)//down
	            {
	            	DELAY_US(SW_DELAY);
	            	VFDPrintf("acc_%d   ",acc);
			    	break;
	            }

				else if(SW_U==0)//up
				{
					DELAY_US(SW_DELAY);
					VFD_RUN();
				}
			
	            else
	            {
	            	VFDPrintf("acc_%d   ",acc);
	            }
    		}
         	//write_acc_handle_rom();
		 	break;
    	}	
	 R_MOT_D();
}

void R_MOT_D(void)// 감속 가속도 조절 함수 
{
	VFDPrintf("HanDecel");
    while(1)
    	{
    	while(1)
    		{
    			DELAY_US(100000);
	            if(SW_R==0)
	            {
	            	DELAY_US(50000);
		        	g_q17_handle_dec += 1;
                	dec+=1;
		        	VFDPrintf("dec_%d   ",dec);
	            }

	            else if(SW_L==0)
	            {
	            	DELAY_US(50000);
		        	g_q17_handle_dec -= 1;
                	dec-=1;
		        	VFDPrintf("dec_%d   ",dec);
	            }

	            else if(SW_D==0)
	            {
	            	DELAY_US(SW_DELAY);
	            	VFDPrintf("dec_%d   ",dec);
			    	break;
	            }

				else if(SW_U==0)
				{
					DELAY_US(SW_DELAY);
					VFD_RUN();
				}
			
	            else
	            {
	            	VFDPrintf("dec_%d   ",dec);
	            }
    		}
         	//write_dec_handle_rom();
		 	break;
    	}	
	 VFD_RUN();
}

////////////////////////////////////////////////////////////////////////////////////////////////////

void End__Acc(void)// 감속 가속도 조절 함수 
{
	VFDPrintf("End_Acc");
    while(1)
    	{
    	while(1)
    		{
    			DELAY_US(100000);
	            if(SW_R==0)
	            {
	            	DELAY_US(10000);
		        	end_accel+= 100;
		        	VFDPrintf("acc%ld    ",end_accel);
	            }

	            else if(SW_L==0)
	            {
	            	DELAY_US(10000);
		        	end_accel -= 100;
		        	VFDPrintf("acc%ld    ",end_accel);
	            }

	            else if(SW_D==0)
	            {
	            	DELAY_US(SW_DELAY);
	            	VFDPrintf("acc%ld    ",end_accel);
			    	break;
	            }

				else if(SW_U==0)
				{
					DELAY_US(SW_DELAY);
					VFD_ACCEL();
				}
			
	            else
	            {
	            	VFDPrintf("acc%ld    ",end_accel);
	            }
    		}
         	//write_dec_handle_rom();
		 	break;
    	}	
	 VFD_ACCEL();
}
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

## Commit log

2025-08-24 main 폴더 추가
2025-08-24 Add project code into 2025_dankook_code/main
    [DSP280x_Adc.obj, DSP280x_CodeStartBranch.obj, DSP280x_CpuTimers.obj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]
2025-08-24 Add project code into 2025_dankook_code/include
    [DSP280x_Adc.obj, DSP280x_CodeStartBranch.obj, DSP280x_CpuTimers.obj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]
2026-05-02 docs: explain multi-stage race flow
2026-05-07 Add PCB design files
2026-05-09 Organize PCB files by year
2026-05-09 Update 2026 motor driver PCB file
2026-05-10 Reorganize software and hardware folders
    [DSP280x_Adc.obj, DSP280x_CodeStartBranch.obj, DSP280x_CpuTimers.obj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]
2026-05-10 Update 2026 PCB and add mechanics assets
    [26년 스텝밑판.STL, 송성혁_가드.STL, 송성혁_모터.STL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]
2026-07-04 Add 2026 custom STM board project
2026-07-07 Organize 2026 PCB files by tracer platform
2026-07-24 Add STM 3rd code
    [DSP280x_Adc.obj, DSP280x_CodeStartBranch.obj, DSP280x_CpuTimers.obj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]
2026-07-24 Rename TMS initial code folder
    [DSP280x_Adc.obj, DSP280x_CodeStartBranch.obj, DSP280x_CpuTimers.obj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]
2026-07-29 Sync current STM 3rd code before handle slew tuning
2026-07-29 Sync current STM tracer tuning
2026-08-06 Fix STM sensor buzzer polarity
    [sensor.c]
2026-08-13 Document STM32 position low-pass filter
